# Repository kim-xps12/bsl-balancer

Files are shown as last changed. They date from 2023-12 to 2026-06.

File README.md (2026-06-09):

# BSL-Balancer (ﾀｲﾘﾝﾁｬﾝ)

## About
BSL-Balancerは手乗りサイズの学習向け対向二輪型倒立振子です．
M5Stack Core2とDYNAMIXEL XL330を主軸に3Dプリンタ製のボディで構成することで，コストと性能のバランス両立を目指しました．
ｽﾀｯｸﾁｬﾝ*と同じ[m5stack-avatar](https://github.com/meganetaaan/m5stack-avatar)による顔を設定することで親しみやすいデザインに．対向二輪型倒立振子タイプのｽﾀｯｸﾁｬﾝ，「ﾀｲﾘﾝﾁｬﾝ」とお呼びください．画面右上の髪飾りは大輪の花を表しています．

BSL-Balancer is a Palm-sized, two-wheeled inverted pendulum educational use.
By constructing a 3D printed body with M5Stack Core2 and DYNAMIXEL XL330 as the main components, I aimed to achieve a balance between cost and performance.
It has a friendly design with a face created by [m5stack-avatar](https://github.com/meganetaaan/m5stack-avatar), which is the same as stack-chan*. This is a two-wheeled inverted pendulum type Stack Chan, please call me "Tairin-chan".The hair ornament at the top right of the screen represents a "large flower (in japanese, Tairin-no-hana)."

*ｽﾀｯｸﾁｬﾝは[ししかわ](https://twitter.com/stack_chan)さんが開発，公開している， 手乗りサイズのｽｰﾊﾟｰｶﾜｲｲコミュニケーションロボットです．リポジトリ：https://github.com/meganetaaan/stack-chan

*stack-chan is a hand-sized super cute communication robot developed and published by [Shishikawa](https://twitter.com/stack_chan)-san. Repository: https://github.com/meganetaaan/stack-chan

**front**
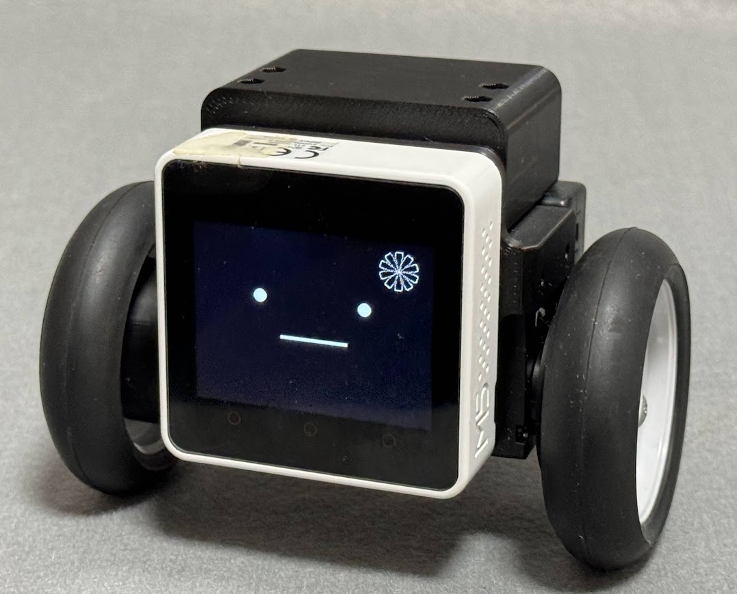
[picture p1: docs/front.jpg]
front


**back**
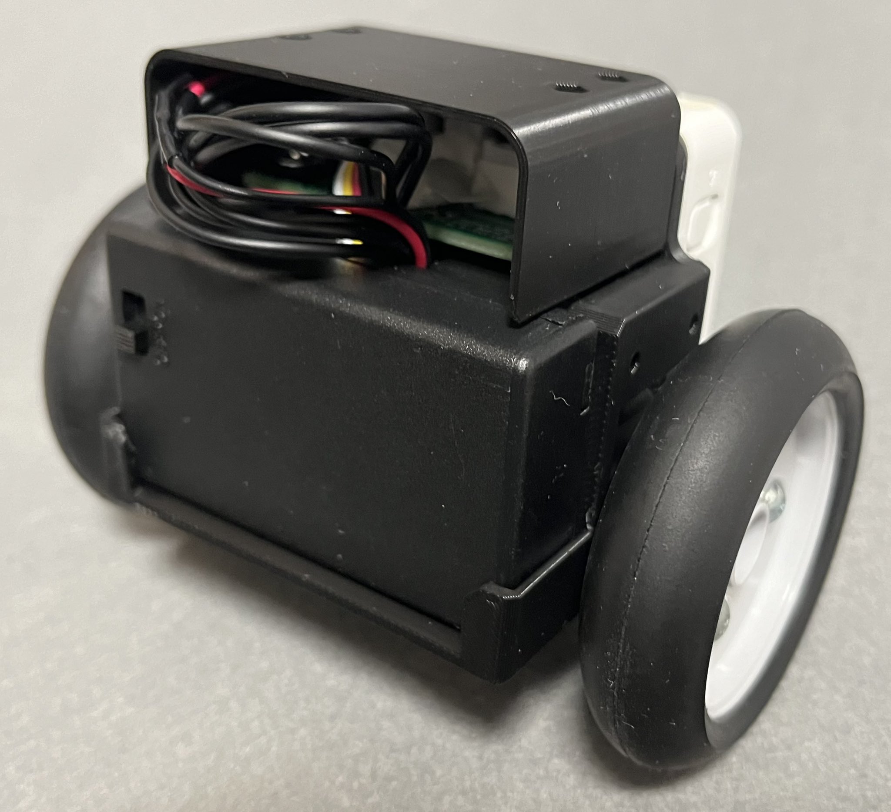
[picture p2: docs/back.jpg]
back


## BOM

| | | | |
| --- | --- | --- | --- |
| **Item** | **Model** | **Qty.** | **Link** |
| MCU | M5Stack Core2<br> | 1 pc. | [SWITCH SCIENCE](https://ssci.to/9349), <br> [Sengoku](https://www.sengoku.co.jp/mod/sgk_cart/detail.php?code=EEHD-68G8) |
| Servo Motor<br> | DYNAMIXEL XL330-M077-T | 2 pcs. | [ROBOTIS e-shop](https://e-shop.robotis.co.jp/product.php?id=416), <br> [RT-shop](https://www.rt-shop.jp/index.php?main_page=product_info&products_id=3902) |
| Servo IF Board | B-SKY Lab Original Board | 1 pc. | [GitHub](https://github.com/kim-xps12/m5stack_board_dynamixel_ttl_rs3485) |
| Cable | M5STACK-CABLE-10 | 1 pc. | [SWITCH SCIENCE](https://www.switch-science.com/products/5213 "https://www.switch-science.com/products/5213"), <br> [Sengoku](https://www.sengoku.co.jp/mod/sgk_cart/detail.php?code=EEHD-5CLV) |
| Tire Unit | TAMIYA Narrow Tire | 1 set | [Amazon](https://amzn.asia/d/4A3hlcZ) |
| Battery | AAA Type | 3 pcs. | \-  |
| Battery Box | SBH-431-1AS150 | 1 pc. | [Akizuki](https://akizukidenshi.com/catalog/g/g103196/) |
| XH Connector Housing| XHP-2 | 1 pc. | [Akizuki](https://akizukidenshi.com/catalog/g/g112255/) |
| XH Connector Contact| SXH-001T-P0.6 | 1 pack | [Akizuki](https://akizukidenshi.com/catalog/g/g112264/) |
| Body (3D-Printed Parts) | B-SKY Lab Original parts  | 1 set | This repository |
| Magnet | D=6mm, t=3mm| 4 pcs. | [DAISO](https://jp.daisonet.com/products/4549131156621) |
| M3 Hex Nut | class 1 in JIS | 10 pcs. |-|
| M3 Bolt | L=10mm (for top cover)  | 4 pcs. |-|
| M3 Bolt | L=12mm (for tire)  | 6 pcs. |-|

## Environment
- PlatformIO on Visual Studio Code
- ~~Arduino IDE on Windows 11 (please apply M5Stack setting)~~

**NOTE**

このリポジトリではArduino IDEのサポートのサポートを終了しました．
`for_arduino_ide`に以前までのコードを保存しているので，サンプルとしての利用は可能です．
Arduino IDEで開発される場合は，これをベースにPIO向けのコードの内容を手動で反映させることでお使いいただけます．

This repository no longer supports Arduino IDE.
The previous code is saved in `for_arduino_ide`, so it can be used as a example.
If you are developing with Arduino IDE, you can use this as a base by manually reflecting the contents of the code in PIO code.

## Parts 3D-Print and Assembly
- please refer **fron** and **back** view.
- manual: coming soon !

### Battery Box

[基板のREADMEのピンアサイン](https://github.com/kim-xps12/m5stack_board_dynamixel_ttl_rs3485?tab=readme-ov-file#pin-assign)を参考に，電池ボックスにXHコネクタを取り付けてください．

Crimp the XH connector to the battery box, referring to the [pin assignment in the README of the board](https://github.com/kim-xps12/m5stack_board_dynamixel_ttl_rs3485?tab=readme-ov-file#pin-assign).

### Change baudrate of XL330

お好みのDYNAMIXEL開発環境，あるいは[m5core2_dynamixel_wizard](https://github.com/kim-xps12/m5core2_dynamixel_wizard)をM5Stack Core2へ書き込んで利用し，使用するDYNAMIXEL XL330のBaudrateを`1000000`に設定してください．

Use your preferred DYNAMIXEL development environment or [m5core2_dynamixel_wizard](https://github.com/kim-xps12/m5core2_dynamixel_wizard) to write it to the M5Stack Core2 and set the Baudrate of the DYNAMIXEL XL330 you are using to `1000000`.

## Usage

### How to stand up

1. 電池ボックスの電源スイッチをONにします
    
    Turn on the power switch on the battery box.
   
1. M5Stack Core2の画面が鉛直になるように手で支えて保持します

    Manually hold and support the M5Stack Core2 so that its screen is vertical.

1. M5Stack Core2の電源をONにします

    Turn on the power of the M5Stack Core2.

1. ゆっくりと手を離すと倒立します

    Release your hand and it will stand up.

もし難しい場合は，次の手順を試してみてください．

If you find this difficult, please try the following steps:

1. 先にM5Stack Core2の電源をONにします

    First, turn on the power of the M5Stack Core2.

1. 電池ボックスの電源スイッチをONにします

    Turn on the power switch on the battery box.

1. M5Stack Core2の画面が鉛直になるように手で支えて保持します

    Manually hold and support the M5Stack Core2 so that its screen is vertical.
   
1. M5Stack Core2のリセットボタン（本体下部側のボタン）を短く押して離します

    Press shortly and release the reset button located at the bottom side of the device.

1. ゆっくりと手を離すと倒立します

    Release your hand and it will stand up.

### How to tune parameters

1. ボタンB（中央）をタップしてコントロールパネルを表示します

    Tap the B button (middle) to display the control panel.

1. [+]ボタンまたは[-]ボタンでパラメータ（P, I, D各ゲインと目標角度）を変更できます

    Use the [+] or [-] buttons to change parameters (P, I, D gains, and target angle).

**NOTE**
設定したパラメータは電源の再投入などのリセットで失われます．EEPROMに保存する機能は今後追加される予定です．

The configured parameters will be lost upon reset, such as when the power is cycled. A feature to save settings to EEPROM will be added in the future.

## Reference

- トランジスタ技術2019年7月号　月着陸船アポロに学ぶ確率統計コンピュータ: [https://cc.cqpub.co.jp/lib/system/doclib\_library/detail/81368/](https://cc.cqpub.co.jp/lib/system/doclib_library/detail/81368/)

- HomeMadeGarbage SHISEIGYO-1DC Plus Recipe: [https://shop.homemadegarbage.com/product/s-1\_dc-plus\_recipe/](https://shop.homemadegarbage.com/product/s-1_dc-plus_recipe/)

- HomeMadeGarbage フルスケールレンジの変更 (MPU6886): [https://homemadegarbage.com/reactionwheel06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](https://homemadegarbage.com/reactionwheel06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)

- M5Unified入門 その1 概要確認 #IMU: [https://lang-ship.com/blog/work/m5unified-1/#toc16](https://lang-ship.com/blog/work/m5unified-1/#toc16)

- M5StickCの6軸入力から姿勢を求める(カルマンフィルタ編): [https://shiker.hatenablog.com/entry/2019/08/24/004637](https://shiker.hatenablog.com/entry/2019/08/24/004637)

- M5Stack Core2 内蔵IMU (MPU6886) Datasheet: [https://github.com/m5stack/M5-Schematic/blob/master/datasheet/MPU-6886-000193%2Bv1.1\_GHIC.PDF.pdf](https://github.com/m5stack/M5-Schematic/blob/master/datasheet/MPU-6886-000193%2Bv1.1_GHIC.PDF.pdf)

- Dynamixel2Arduino: [https://github.com/ROBOTIS-GIT/Dynamixel2Arduino](https://github.com/ROBOTIS-GIT/Dynamixel2Arduino)

- M5Unified: [https://github.com/m5stack/M5Unified](https://github.com/m5stack/M5Unified)

- TKJElectronics KalmanFilter Library: [https://github.com/TKJElectronics/KalmanFilter](https://github.com/TKJElectronics/KalmanFilter)

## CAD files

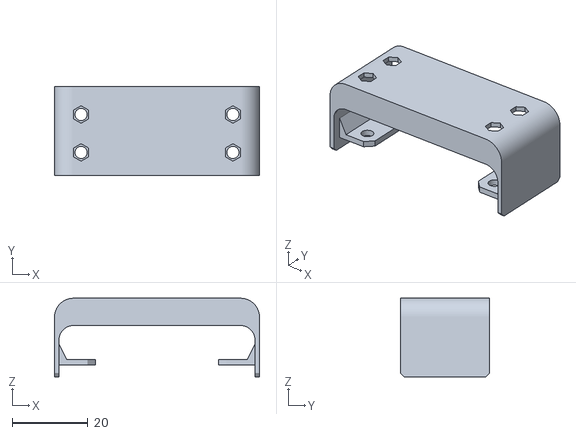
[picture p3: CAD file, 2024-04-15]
case/cover_board_short.stl
54.0 x 23.5 x 20.7

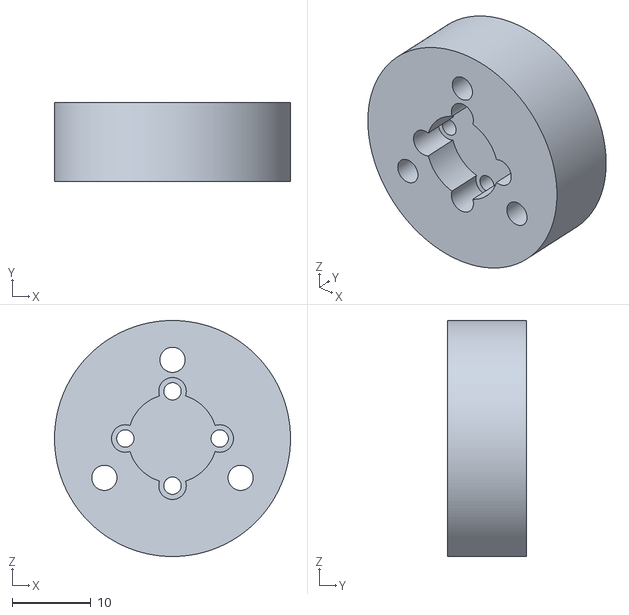
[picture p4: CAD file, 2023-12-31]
case/mout_tire.stl
30.0 x 10.0 x 30.0

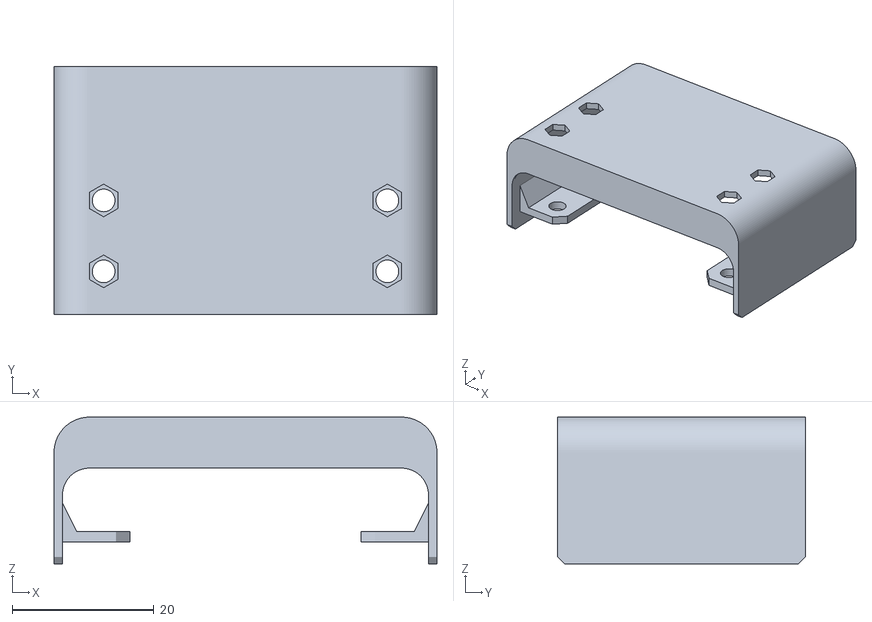
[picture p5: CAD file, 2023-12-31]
case/cover_board.stl
54.0 x 35.0 x 20.7

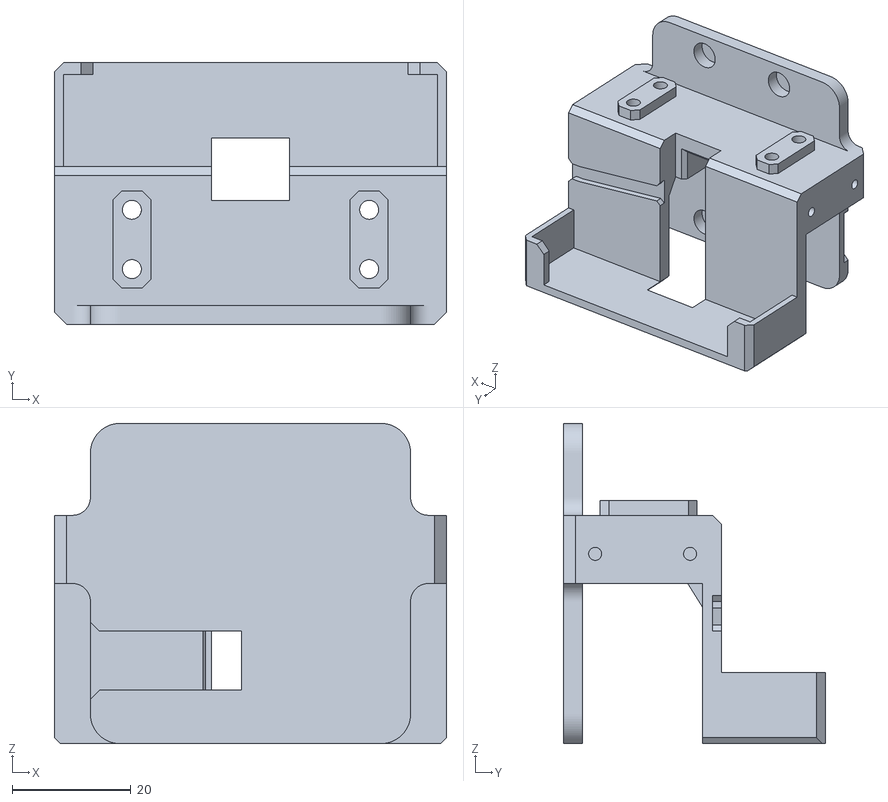
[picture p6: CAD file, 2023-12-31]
case/body.stl
66.1 x 44.1 x 54.0

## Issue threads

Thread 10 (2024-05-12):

サーボの設定手順が未整備

kim-xps12, 2024-05-12:
## いただいたFB

サーボ設定の説明がない。

## 補足

この辺があればよいはず？
- IDの設定方法
- baudrateの変更方法

そもそもbaudrateは2Mもいるのか，1Mでもよいのでは（デフォだとさすがに遅そう）

2Mに変更するスケッチ（とデフォに戻すスケッチ）が同封されてれば2Mでも許容範囲？

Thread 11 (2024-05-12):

IF基板のピンアサインが分かりにくい問題

kim-xps12, 2024-05-12:
## いただいたFB

専用基板のサーボ電源線のプラマイ表記がなく、わかりにくい。

kim-xps12, 2024-05-12:
ピン配置は[基板のリポジトリのこのコミット](https://github.com/kim-xps12/m5stack_board_dynamixel_ttl_rs3485/commit/904eceec98fe5b726c77ccccd42fb0f3f11ef76b)で更新した．

それはそれとして，BOMにXHコネクタ周りも追加する．

kim-xps12, 2024-05-26:
[コミット330b4422](https://github.com/kim-xps12/bsl-balancer/commit/330b4422edc6d2c50027910781ba2463e580d040)でBOMにXHコネクタ周りも追加した．おしまい．

Closed 2024-05-26.

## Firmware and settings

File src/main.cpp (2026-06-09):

#include <Arduino.h>

#include <M5Unified.h>

#include <Preferences.h>
#include <Dynamixel2Arduino.h>
#include <esp_task_wdt.h>
#include <esp_timer.h>
#include "imu_driver.h"

HardwareSerial& DXL_SERIAL = Serial1;

// M5Stack Core2 PORT A pin configuration
const uint8_t PIN_RX_SERVO = 33;
const uint8_t PIN_TX_SERVO = 32;

// Default controller params
const float DEFAULT_KP = 15.0f;
const float DEFAULT_KI = 0.05f;
const float DEFAULT_KD = 0.0f;
const float DEFAULT_PITCH_TARGET = 86.0f;
const TickType_t CTRL_PERIOD_TICKS = pdMS_TO_TICKS(5);  // 200Hz

// DYNAMIXEL Params.
const uint8_t DXL_ID_L = 0;
const uint8_t DXL_ID_R = 1;
const float DXL_PROTOCOL_VERSION = 2.0;

Dynamixel2Arduino dxl;
ImuDriver imuDriver;

// I2C bus mutex
SemaphoreHandle_t g_i2c_mutex = nullptr;

// --- Inter-task communication ---

enum class CtrlCommandType : uint8_t {
    SET_PITCH_TARGET, SET_KP, SET_KI, SET_KD,
};
struct CtrlCommand { CtrlCommandType type; float value; };

struct TelemetryData {
    float pitch_deg;
    float pitch_rate_dps;
    float rpm_cmd;
    float P_term, I_term, D_term;
    uint32_t loop_us;
    bool fallen;
};

QueueHandle_t g_cmd_queue = nullptr;
QueueHandle_t g_telemetry_queue = nullptr;

// --- Motor drive ---

void driveTire(int rpm) {
    dxl.setGoalVelocity(DXL_ID_L, -1 * rpm, UNIT_RPM);
    dxl.setGoalVelocity(DXL_ID_R, rpm, UNIT_RPM);
}

// --- Control task ---

void controlLoopTask(void *pvParameters) {
    esp_task_wdt_add(NULL);
    TickType_t xLastWakeTime = xTaskGetTickCount();

    float kp = DEFAULT_KP;
    float ki = DEFAULT_KI;
    float kd = DEFAULT_KD;
    float target = DEFAULT_PITCH_TARGET;
    float I_acc = 0.0f;
    float preP = 0.0f;
    float D_filtered = 0.0f;
    bool pid_active = false;
    int64_t prev_us = 0;

    while (true) {
        esp_task_wdt_reset();
        int64_t now_us = esp_timer_get_time();

        // Drain pending commands (non-blocking)
        CtrlCommand cmd;
        while (xQueueReceive(g_cmd_queue, &cmd, 0) == pdTRUE) {
            switch (cmd.type) {
                case CtrlCommandType::SET_KP:           kp = cmd.value; break;
                case CtrlCommandType::SET_KI:           ki = cmd.value; break;
                case CtrlCommandType::SET_KD:           kd = cmd.value; break;
                case CtrlCommandType::SET_PITCH_TARGET: target = cmd.value; break;
            }
        }

        // Compute dt from actual elapsed time
        float dt;
        if (prev_us == 0) {
            dt = 0.010f;
        } else {
            dt = (float)(now_us - prev_us) / 1000000.0f;
            dt = constrain(dt, 0.002f, 0.050f);
        }
        prev_us = now_us;

        // IMU read + Mahony fusion
        auto imu = imuDriver.update(dt);
        if (!imu.valid) {
            vTaskDelayUntil(&xLastWakeTime, CTRL_PERIOD_TICKS);
            continue;
        }

        float pitch_filtered = imu.pitch_deg;

        float pitch_error = target - pitch_filtered;

        // Fall detection
        if (pitch_error < -40.0f || 40.0f < pitch_error) {
            driveTire(0);
            I_acc = 0.0f;
            preP = 0.0f;
            D_filtered = 0.0f;
            pid_active = false;
            TelemetryData tel = {pitch_filtered, imu.pitch_rate_dps, 0, 0, 0, 0,
                                 (uint32_t)(esp_timer_get_time() - now_us), true};
            xQueueOverwrite(g_telemetry_queue, &tel);
            vTaskDelayUntil(&xLastWakeTime, CTRL_PERIOD_TICKS);
            continue;
        }

        // PID
        float P_val = pitch_error;
        I_acc += P_val * dt;
        float i_limit = 50.0f / (fabsf(ki) + 1e-6f);
        I_acc = constrain(I_acc, -i_limit, i_limit);

        float D_raw;
        if (!pid_active) {
            D_raw = 0.0f;
            pid_active = true;
        } else {
            D_raw = (P_val - preP) / dt;
        }
        // Low-pass filter on D term (alpha=0.2: heavy smoothing)
        D_filtered = 0.2f * D_raw + 0.8f * D_filtered;
        float D_val = D_filtered;
        preP = P_val;

        float rpm_f = kp * P_val + ki * I_acc + kd * D_val;
        int rpm_motor = constrain((int)rpm_f, -300, 300);
        driveTire(rpm_motor);

        // Telemetry (non-blocking overwrite)
        uint32_t elapsed = (uint32_t)(esp_timer_get_time() - now_us);
        TelemetryData tel = {pitch_filtered, imu.pitch_rate_dps, (float)rpm_motor,
                             P_val, I_acc, D_val, elapsed, false};
        xQueueOverwrite(g_telemetry_queue, &tel);

        vTaskDelayUntil(&xLastWakeTime, CTRL_PERIOD_TICKS);
    }
}

// --- UI helpers ---

void drawButton(const char* label, int x, int y, float value) {
    M5.Display.drawRect(x, y, 50, 30, WHITE);
    M5.Display.drawString("-", x + 20, y, 2);
    M5.Display.drawRect(x + 200, y, 50, 30, WHITE);
    M5.Display.drawString("+", x + 200 + 20, y, 2);
    M5.Display.setCursor(x + 70, y + 5);
    M5.Display.print(label);
    M5.Display.print(": ");
    M5.Display.println(value, 1);
}

// --- UI task ---

static float ui_kp = DEFAULT_KP;
static float ui_ki = DEFAULT_KI;
static float ui_kd = DEFAULT_KD;
static float ui_target = DEFAULT_PITCH_TARGET;
bool enShowCtrlPanel = false;

void drawCtrlPanel() {
    drawButton("Ref", 20, 30, ui_target);
    drawButton("Kp", 20, 70, ui_kp);
    drawButton("Ki", 20, 110, ui_ki);
    drawButton("Kd", 20, 150, ui_kd);

    if (xSemaphoreTake(g_i2c_mutex, pdMS_TO_TICKS(10)) == pdTRUE) {
        int batteryPercentage = M5.Power.getBatteryLevel();
        xSemaphoreGive(g_i2c_mutex);
        M5.Display.setCursor(20, 190);
        M5.Display.printf("M5Core2 Battery: %d%%", batteryPercentage);
    }
}

void handleCtrlPanelTouched() {
    auto pos = M5.Touch.getDetail();
    if (!pos.wasPressed()) return;

    CtrlCommand cmd;
    bool send = true;

    if (pos.y >= 30 && pos.y < 60) {
        if (pos.x >= 15 && pos.x < 120)      ui_target -= 0.2f;
        else if (pos.x >= 220 && pos.x < 270) ui_target += 0.2f;
        else send = false;
        if (send) { cmd = {CtrlCommandType::SET_PITCH_TARGET, ui_target}; drawButton("Ref", 20, 30, ui_target); }
    }
    else if (pos.y >= 70 && pos.y < 100) {
        if (pos.x >= 15 && pos.x < 120)      ui_kp -= 0.2f;
        else if (pos.x >= 220 && pos.x < 270) ui_kp += 0.2f;
        else send = false;
        if (send) { cmd = {CtrlCommandType::SET_KP, ui_kp}; drawButton("Kp", 20, 70, ui_kp); }
    }
    else if (pos.y >= 110 && pos.y < 140) {
        if (pos.x >= 15 && pos.x < 120)      ui_ki -= 0.2f;
        else if (pos.x >= 220 && pos.x < 270) ui_ki += 0.2f;
        else send = false;
        if (send) { cmd = {CtrlCommandType::SET_KI, ui_ki}; drawButton("Ki", 20, 110, ui_ki); }
    }
    else if (pos.y >= 150 && pos.y < 180) {
        if (pos.x >= 15 && pos.x < 120)      ui_kd -= 0.2f;
        else if (pos.x >= 220 && pos.x < 270) ui_kd += 0.2f;
        else send = false;
        if (send) { cmd = {CtrlCommandType::SET_KD, ui_kd}; drawButton("Kd", 20, 150, ui_kd); }
    }
    else {
        send = false;
    }

    if (send) xQueueSend(g_cmd_queue, &cmd, 0);
}

void uiLoopTask(void *pvParameters) {
    TickType_t xLastWakeTime = xTaskGetTickCount();
    uint32_t last_telemetry_ms = 0;

    while (true) {
        if (xSemaphoreTake(g_i2c_mutex, pdMS_TO_TICKS(10)) == pdTRUE) {
            M5.update();
            xSemaphoreGive(g_i2c_mutex);
        }

        // Toggle tuning panel
        if (M5.BtnB.wasPressed()) {
            enShowCtrlPanel = !enShowCtrlPanel;
            M5.Lcd.clear();
            if (enShowCtrlPanel) drawCtrlPanel();
        }

        if (enShowCtrlPanel) {
            handleCtrlPanelTouched();
        }

        // Telemetry output via Serial (10Hz)
        uint32_t now_ms = millis();
        TelemetryData tel;
        if (now_ms - last_telemetry_ms >= 100) {
            if (xQueuePeek(g_telemetry_queue, &tel, 0) == pdTRUE) {
                last_telemetry_ms = now_ms;
                Serial.printf(">pitch:%.2f\n>rate:%.2f\n>rpm:%.1f\n>P:%.2f\n>I:%.3f\n>D:%.2f\n>loop_us:%u\n",
                              tel.pitch_deg, tel.pitch_rate_dps, tel.rpm_cmd,
                              tel.P_term, tel.I_term, tel.D_term, tel.loop_us);
            }
        }

        vTaskDelayUntil(&xLastWakeTime, pdMS_TO_TICKS(50));
    }
}

// --- Setup ---

void setup() {
    Serial.begin(115200);

    auto cfg = M5.config();
    cfg.internal_rtc = false;
    cfg.internal_mic = false;
    cfg.internal_spk = false;
    cfg.internal_imu = true;
    M5.begin(cfg);
    M5.Lcd.fillScreen(BLACK);
    M5.Lcd.setTextSize(2);
    M5.Lcd.setCursor(0, 0);

    // I2C mutex
    g_i2c_mutex = xSemaphoreCreateMutex();
    configASSERT(g_i2c_mutex != nullptr);

    // Inter-task queues
    g_cmd_queue = xQueueCreate(8, sizeof(CtrlCommand));
    g_telemetry_queue = xQueueCreate(1, sizeof(TelemetryData));
    configASSERT(g_cmd_queue != nullptr);
    configASSERT(g_telemetry_queue != nullptr);

    // DYNAMIXEL Settings
    DXL_SERIAL.begin(1000000, SERIAL_8N1, PIN_RX_SERVO, PIN_TX_SERVO);
    dxl = Dynamixel2Arduino(DXL_SERIAL);
    dxl.begin(1000000);
    dxl.setPortProtocolVersion(DXL_PROTOCOL_VERSION);

    if (!dxl.ping(DXL_ID_L)) { M5.Lcd.println("DXL L ping FAIL"); }
    if (!dxl.ping(DXL_ID_R)) { M5.Lcd.println("DXL R ping FAIL"); }
    dxl.torqueOff(DXL_ID_L);
    dxl.torqueOff(DXL_ID_R);
    dxl.setOperatingMode(DXL_ID_L, OP_VELOCITY);
    dxl.setOperatingMode(DXL_ID_R, OP_VELOCITY);
    dxl.torqueOn(DXL_ID_L);
    dxl.torqueOn(DXL_ID_R);

    // IMU driver init + calibration
    imuDriver.begin(g_i2c_mutex);
    M5.Lcd.println("Calibrating...");
    imuDriver.calibrate(500, 0.5f);
    M5.Lcd.println("Ready!");

    // WDT
    esp_task_wdt_init(1, true);

    // RTOS Tasks
    const uint32_t MEMORY_STACK = 8192;
    xTaskCreatePinnedToCore(controlLoopTask, "Control", MEMORY_STACK, NULL, 20, NULL, 1);
    xTaskCreatePinnedToCore(uiLoopTask,      "UI",      MEMORY_STACK, NULL, 3,  NULL, 0);
}

void loop() {
}

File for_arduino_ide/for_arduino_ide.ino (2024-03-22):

#include <M5Unified.h>
#include <Kalman.h>
#include <Preferences.h>
#include <Dynamixel2Arduino.h>

HardwareSerial& DXL_SERIAL = Serial1;
#define DEBUG_SERIAL Serial
#define ENABLE_DEBUG_PRINT

// Contoller Params. 
const TickType_t xPeriodMs = 10;  // [milli sec]
float Kp = 50.0;
float Ki = 1.0;
float Kd = 1.0;

float pitch_target = 86.0; //[deg]

float P = 0.0;
float I = 0.0;
float D = 0.0;
float preP = 0.0;


// Kalman filter Params.
Kalman kalman;
float accX, accY, accZ;
float gyroX, gyroY, gyroZ;


// Contoller Values
unsigned long previousTimestamp = 0;
unsigned long currentTimestamp = 0;
unsigned long elapsedTime = 0;


// DYNAMIXEL Params.
const uint8_t DXL_ID_L = 0;
const uint8_t DXL_ID_R = 1;
const float DXL_PROTOCOL_VERSION = 2.0;

Dynamixel2Arduino dxl;//(DXL_SERIAL);

float getPitch(){
  M5.Imu.getAccelData(&accX, &accY, &accZ);
  float pitch = atan2(accY, accZ) * RAD_TO_DEG; //[deg]
  return pitch;
}


float getPitchDot() {
  M5.Imu.getGyroData(&gyroX, &gyroY, &gyroZ);
  float pitch_dot = gyroX;
  return pitch_dot;  //[deg/sec]
}


void driveTire(int rpm) {

  // Set Goal Velocity using RPM
  dxl.setGoalVelocity(DXL_ID_L, -1*rpm, UNIT_RPM);
  dxl.setGoalVelocity(DXL_ID_R, rpm, UNIT_RPM);

  #ifdef ENABLE_DEBUG_PRINT
  DEBUG_SERIAL.print("Present Velocity(rpm)--L : ");
  DEBUG_SERIAL.print(dxl.getPresentVelocity(DXL_ID_L, UNIT_RPM));
  DEBUG_SERIAL.print(", R : ");
  DEBUG_SERIAL.println(dxl.getPresentVelocity(DXL_ID_R, UNIT_RPM));
  #endif
}


void controlLoopTask(void *pvParameters) {
    TickType_t xLastWakeTime = xTaskGetTickCount();

    while(true) {
      calcPID();
      vTaskDelayUntil(&xLastWakeTime, xPeriodMs);
    }
}


void uiLoopTask(void *pvParameters){
  
  TickType_t xLastWakeTime = xTaskGetTickCount();  
  while(true){
    M5.update();

    bool isReleased = true;
    if (M5.Touch.getCount() > 0 ) {
      isReleased = false;
      auto pos = M5.Touch.getDetail();

      if(pos.wasPressed()){
        // 各ボタンのタッチ確認
        if (pos.y >= 30 && pos.y < 60) { // Target
          if (pos.x >= 15 && pos.x < 120) pitch_target-=0.2;
          else if (pos.x >= 220 && pos.x < 270) pitch_target+=0.2;
          drawButton("Ref", 20, 30, pitch_target);
        }
        else if (pos.y >= 70 && pos.y < 100) {
          if (pos.x >= 15 && pos.x < 120) Kp-=0.2;
          else if (pos.x >= 220 && pos.x < 270) Kp+=0.2;
          drawButton("Kp", 20, 70, Kp);
        }
        else if (pos.y >= 110 && pos.y < 140) { // Ki
          if (pos.x >= 15 && pos.x < 120) Ki-=0.2;
          else if (pos.x >= 220 && pos.x < 270) Ki+=0.2;
          drawButton("Ki", 20, 110, Ki);
        }
        else if (pos.y >= 150 && pos.y < 180) { // Kd
          if (pos.x >= 15 && pos.x < 120) Kd-=0.2;
          else if (pos.x >= 220 && pos.x < 270) Kd+=0.2;
          drawButton("Kd", 20, 150, Kd);
        }
      }
    }
    vTaskDelayUntil(&xLastWakeTime, xPeriodMs*5);
  }
}

void calcPID(){

  currentTimestamp = micros();
  elapsedTime = currentTimestamp - previousTimestamp;
  previousTimestamp = currentTimestamp;
  
  float dt = (float)xPeriodMs /1000; // [sec]
  float pitch_kalman = kalman.getAngle(getPitch(), getPitchDot(), dt);
  float pitch_dot_kalman = kalman.getRate();

  float pitch_error = pitch_target - pitch_kalman;

  // M5.Lcd.clear();
  // M5.Lcd.setCursor(0, 0);
  // M5.Lcd.println(pitch_kalman);
  // M5.Lcd.println(elapsedTime);

  if(pitch_error < -40 || 40 < pitch_error) {
    driveTire(0);
    P = 0;
    I = 0;
    D = 0;
    return;
  }

  P = pitch_target - pitch_kalman;
  I += P * dt;
  D = (P - preP) / dt;
  preP = P;

  // anti windup
  if (200 < abs(I * Ki)) {
    I = 0;
  }
    
  // Calclate Motor Output
  int rpm_motor = Kp * P + Ki * I + Kd * D;
  rpm_motor = constrain(rpm_motor, -300, 300);
  driveTire(rpm_motor);
  //DEBUG_SERIAL.println(pitch_kalman);

}


void drawButton(const char* label, int x, int y, float value) {
  // ボタンの描画
  M5.Display.drawRect(x, y, 50, 30, WHITE);
  M5.Display.drawString("-", x+20, y, 2);

  M5.Display.drawRect(x+200, y, 50, 30, WHITE);
  M5.Display.drawString("+", x+200+20, y, 2);
  
  // ラベルと値の描画
  M5.Display.setCursor(x+70, y+5);
  M5.Display.print(label);
  M5.Display.print(": ");
  M5.Display.println(value, 1);
}

void setup(){

  DXL_SERIAL.begin(2000000, SERIAL_8N1, 32, 33);
  dxl = Dynamixel2Arduino(DXL_SERIAL);

  // M5 Settings
  M5.begin();
  M5.Lcd.fillScreen(BLACK);
  M5.Lcd.setTextSize(2);
  M5.Lcd.setCursor(0, 0);
  
  drawButton("Ref", 20, 30, pitch_target);
  drawButton("Kp", 20, 70, Kp);
  drawButton("Ki", 20, 110, Ki);
  drawButton("Kd", 20, 150, Kd);
  
  M5.Imu.init();
  // M5.Imu.setAccelFsr(M5.Imu.AFS_2G);
  // M5.Imu.setGyroFsr(M5.Imu.GFS_250DPS);

  DEBUG_SERIAL.begin(115200);

  // DYNAMIXEL Settings
  dxl.begin(2000000);  // DYNAMIXEL baudrate.
  dxl.setPortProtocolVersion(DXL_PROTOCOL_VERSION);
  dxl.ping(DXL_ID_L);
  dxl.ping(DXL_ID_R);
  dxl.torqueOff(DXL_ID_L);  // Turn off torque when configuring items in EEPROM area
  dxl.torqueOff(DXL_ID_R); 
  dxl.setOperatingMode(DXL_ID_L, OP_VELOCITY);
  dxl.setOperatingMode(DXL_ID_R, OP_VELOCITY);
  dxl.torqueOn(DXL_ID_L);
  dxl.torqueOn(DXL_ID_R);

  kalman.setAngle(getPitch());
  
  const uint32_t MEMORY_STACK = 8192;
  const UBaseType_t PRIORIRY_SPIN_MAIN = 5;
  //const BaseType_t ID_CORE_CTRL_MAIN = 0;
  xTaskCreatePinnedToCore(controlLoopTask, "Control Loop Task", MEMORY_STACK, NULL, PRIORIRY_SPIN_MAIN, NULL, 0);
  const UBaseType_t PRIORIRY_SPIN_SUB = 2;
  //const BaseType_t ID_CORE_CTRL_SUB = 0;
  xTaskCreatePinnedToCore(uiLoopTask,      "UI Loop Task",      MEMORY_STACK, NULL, PRIORIRY_SPIN_SUB,  NULL, 1);
}


void loop(){
  
}

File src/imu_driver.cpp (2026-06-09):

#include "imu_driver.h"
#include <cmath>

void ImuDriver::begin(SemaphoreHandle_t i2c_mutex) {
    _i2c_mutex = i2c_mutex;
    _pitch_est = 0.0f;
    _gyro_bias = 0.0f;
}

ImuDriver::Data ImuDriver::update(float dt) {
    Data result = {0, 0, false};

    if (xSemaphoreTake(_i2c_mutex, pdMS_TO_TICKS(2)) != pdTRUE) {
        return result;
    }
    auto mask = M5.Imu.update();
    xSemaphoreGive(_i2c_mutex);

    if (!mask) return result;

    auto imu = M5.Imu.getImuData();

    float ay = imu.accel.y;
    float az = imu.accel.z;
    float gx = imu.gyro.x * DEG_TO_RAD;

    float accel_pitch = atan2f(ay, az);
    float error = accel_pitch - _pitch_est;

    _gyro_bias += KI_MAHONY * error * dt;

    float gyro_corrected = gx + KP_MAHONY * error + _gyro_bias;

    _pitch_est += gyro_corrected * dt;

    result.pitch_deg = _pitch_est * RAD_TO_DEG;
    result.pitch_rate_dps = gyro_corrected * RAD_TO_DEG;
    result.valid = true;
    return result;
}

void ImuDriver::calibrate(uint16_t n_samples, float max_stddev_deg) {
    float sum = 0.0f;
    float sum_sq = 0.0f;

    for (uint16_t i = 0; i < n_samples; i++) {
        if (xSemaphoreTake(_i2c_mutex, pdMS_TO_TICKS(10)) == pdTRUE) {
            M5.Imu.update();
            xSemaphoreGive(_i2c_mutex);
        }
        auto imu = M5.Imu.getImuData();
        float pitch = atan2f(imu.accel.y, imu.accel.z) * RAD_TO_DEG;
        sum += pitch;
        sum_sq += pitch * pitch;
        vTaskDelay(pdMS_TO_TICKS(2));
    }

    float mean = sum / n_samples;
    float variance = (sum_sq / n_samples) - (mean * mean);
    float stddev = sqrtf(fabsf(variance));

    if (stddev > max_stddev_deg) {
        Serial.printf("IMU cal: stddev=%.2f > %.2f (vibration?)\n", stddev, max_stddev_deg);
    }

    _pitch_est = mean * DEG_TO_RAD;
    _gyro_bias = 0.0f;

    Serial.printf("IMU cal: pitch=%.2f deg, stddev=%.3f (%d samples)\n", mean, stddev, n_samples);
}

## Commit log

2024-03-22 Feature/support pio (#1)
    * rename arduino IDE directory
    * Fix to eliminate the need to modify the Dynamixel2Arduino library
    * Ported code for Arduino to PlatformIO
    * update About, BOM, and Environment
    * smal update README.md
    [for_arduino_ide.ino, main.cpp]
2024-04-07 Feature/add face (#2)
    * add face, small refactoring
    * update ini
    * add face, small refactoring
    * delete unnecessary calling drawCtrlPanel()
    * delete cheeks
    * add drawing flower
    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
    [TairinEye.cpp, main.cpp]
2024-04-15 fix BOM (battery quty. and battery box)
2024-04-15 add battery level (core2 internal) in control panel (#5)
2024-04-15 add short cover for SBH-441AS (#6)
    [cover_board_short.stl]
2024-05-26 Update BOM (add XH Connector)
2025-09-09 Feature/update versions (#13)
    * update lib_deps
    * update pin assign for DYNAMIXEL-IF-Board v2.0
    * add baudrate setting section
2026-06-09 制御タスクを Core 1 へ移動し platform バージョンを固定 (#15)
    - controlLoopTask: Core 0→1, 優先度 5→20（WiFi/BT 非干渉コアで実行）
    - uiLoopTask: Core 1→0, 優先度 2→3
    - espressif32@6.10.0 に固定しビルド再現性を確保
2026-06-09 制御タスクにウォッチドッグタイマーを登録 (#16)
    * 制御タスクを Core 1 へ移動し platform バージョンを固定
    * 制御タスクにウォッチドッグタイマーを登録
    - esp_task_wdt_init(1秒, panic=true) で WDT 初期化
    - controlLoopTask 開始時に esp_task_wdt_add、毎サイクル esp_task_wdt_reset
    - I2C ハング等で制御ループが 1 秒停止するとシステムリセット発動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
2026-06-09 I2C mutex + IMU バースト読み + 選択的初期化 + Avatar 無効化 (#17)
    - I2C バス排他制御: xSemaphoreCreateMutex で IMU 読み出しと
    M5.update()/getBatteryLevel() を mutex 保護
    - IMU バースト読み: getPitch()+getPitchDot() の分割読みを
    M5.Imu.update() 14byte 一括読みに置換（時間整合性改善）
    - 選択的 M5.begin(cfg): RTC/MIC/SPK を無効化、冗長な M5.Imu.init() を削除
    - Avatar 無効化: avatar.init() を停止し描画タスクによる CPU/SPI 消費を排除
    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
2026-06-09 スレッド安全性・実測 dt・anti-windup・テレメトリキュー・タッチ修正 (#18)
    - P4: UI→制御のコマンドキュー導入（Kp/Ki/Kd/target のスレッド安全な受け渡し）
    - P7: DXL ping 戻り値チェック + 失敗時 LCD 表示
    - P9: anti-windup を I=0 リセットから constrain クランプに改善
    - P10: esp_timer_get_time() による実測 dt（固定値 dt 廃止）
    - P12: 制御→UI テレメトリキュー（xQueueOverwrite）+ Teleplot 形式 10Hz 出力
    - P14: タッチ入力を wasPressed() エッジ検出に修正（repeat バグ解消）
    - P15: #ifdef ENABLE_DEBUG_PRINT の DXL blocking read を完全削除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
    [main.cpp]
2026-06-09 Kalman→Mahony AHRS 置換 + PID ゲイン再調整 (#19)
    - ImuDriver クラス新設（include/imu_driver.h, src/imu_driver.cpp）
    1軸簡略化 Mahony AHRS（KP=2.0, KI=0.005）
    起動時 500 サンプルキャリブレーション付き
    - Kalman Filter Library を lib_deps から削除
    - PID ゲインを Mahony 応答特性に合わせて再調整
    Kp=15, Ki=0.05, Kd=0（D項はローパスフィルタ付きで将来有効化可能）
    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
2026-06-09 制御ループを 200Hz に引き上げ（pdMS_TO_TICKS 統一）
    - configTICK_RATE_HZ=1000 を実機確認済み（Tier 1 成功）
    - 制御周期を 10ms (100Hz) → 5ms (200Hz) に変更
    - raw tick 定数 xPeriodMs を pdMS_TO_TICKS(5) に置換
    - loop_us ~2710us で 5000us 予算に余裕あり
